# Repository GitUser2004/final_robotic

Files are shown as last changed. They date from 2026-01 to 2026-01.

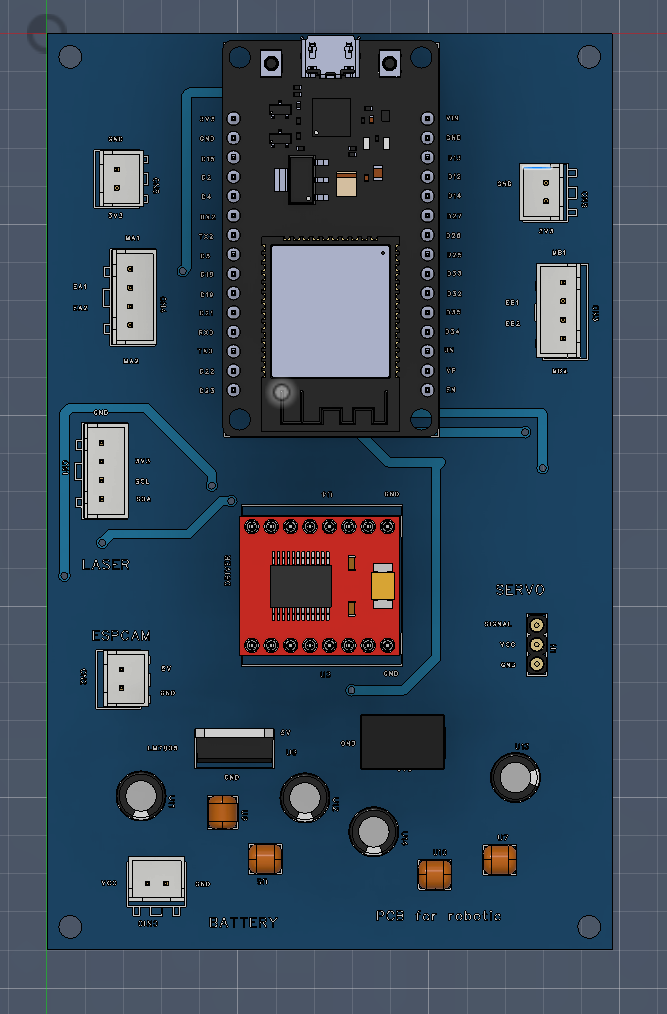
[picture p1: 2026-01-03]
screenshots/Captura de pantalla 2026-01-03 084741.png

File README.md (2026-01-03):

# final_robotic

this repository explains the "Autonomous Mobile Robot for Indoor Medicine Delivery Using Color-Based Vision and Micro-ROS", and implementation of a low-cost autonomous mobile robot for indoor medicine delivery in hospital-like environments. The proposed system integrates color-based computer vision, wireless communication, and reactive navigation to autonomously reach designated rooms identified by color markers while safely avoiding dynamic obstacles. The robot architecture is based on an ESP32 microcontroller, an ESP32-CAM vision system using OpenCV, and a modular control structure compatible with micro-ROS. The delivery task is initiated through a numeric command sent from a user interface, which is mapped to a target color corresponding to a specific room. The robot continuously processes visual data to detect the target color and estimate distance based on detected circular markers, while obstacle avoidance is handled through a low-cost scanning distance sensor. Experimental results demonstrate that the robot can successfully navigate toward target locations, adapt to unexpected obstacles, and complete delivery tasks without human intervention. The modular architecture allows scalability and future integration of advanced localization and planning techniques. This work contributes a flexible, affordable solution for autonomous indoor delivery systems, particularly suited for healthcare and educational environments.

## Environment Setup

### Prerequisites

Ensure you have the following installed:

#### Arduino IDE (Micro-ros)

For programming the esp32 DevKit1 and the espcam its necessary to install the followings libraries in Arduino IDE:

```bash
esp_camera.h
WiFi.h
WebServer.h

# all of this libraries are neccesary only for programming the espcam, otherwise there are additional instrucctions inside the code

WiFi.h
Wire.h
VL53L0X.h
ESP32Servo.h
WebServer.h
PubSubClient.h
ArduinoJson.h
# micro-ROS
micro_ros_arduino.h

# this libraries are for programming the principal esp32, it needs to be updated
```

### Python

```bash
# Install this libraries in python for the espcam
pip install opencv-python==4.11.0.86
pip install numpy==2.3.1

# This dependencies are for the "artificial vision" in the recognition of the colors
```

### ROS2 HUMBLE

```bash

sudo apt install ros-humble-desktop
sudo apt install ros-humble-ros-base
sudo apt install ros-dev-tools
# Check ROS2 Humble installation
ros2 --version
```

In the "esp-cam" folder there are two archives, the .ino is for programming the espcam, this only needs to be with power, the .py in the folder is on ly for visualize the camera in live, otherwise is not neccesary, the camera will works anyway.

### Create Workspace

```bash
# Create and build workspace
mkdir -p ~/autonomous_ws/
cd ~/autonomous_ws/
```

the following steps are neccesary for the first exercise
- copy all the files in the path **ros2/src/dqn_robot_nav/dqn_robot_nav/environment.py** is necessary to copy the folder **src** in the workspace **autonomous_ws**
- make a colcon build
```bash
colcon build
source install/setup.bash
```

once al this steps will be complet it will be ready for running

in one terminal and in the workspace
```bash
ros2 run decision_node decision_node
```
and the interface between the misions and the esp32 will be complete

For testing:
```bash
ros2 topic list
```
to see the nodes.

For the last step is needed to running docker for wifi (for this is neccesary to be in the same network)
```bash
docker run -it --rm --net=host microros/micro-ros-agent:humble udp4 --port 8888 -v6
```

## Interface
The following link is to access to interact with all:
**https://lauch01.github.io/robotic_web/**

To use the interface, the following steps:

1. **Select the room (A, B, C, D)**
2. **Set an hour**

## Extras

In the folders **screenshots**, **3d_models** and **circuit-design** are all the files to build the robot, between .stl, .json and references of components and parts.
- .json files are to import in easyeda pro to view the 3d model

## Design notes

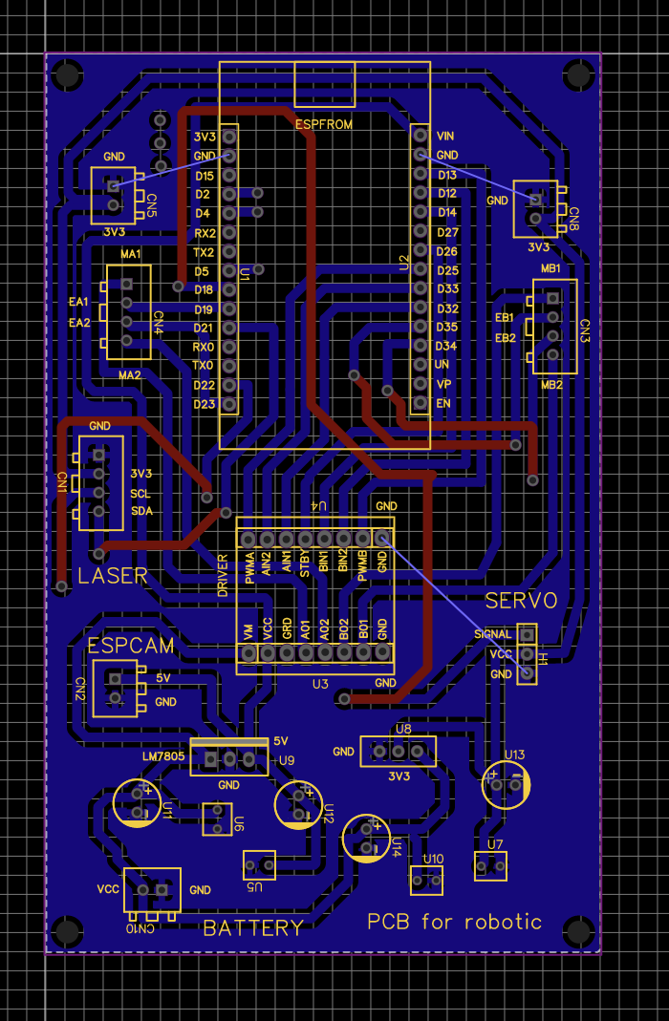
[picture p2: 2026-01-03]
circuit_design/image.png

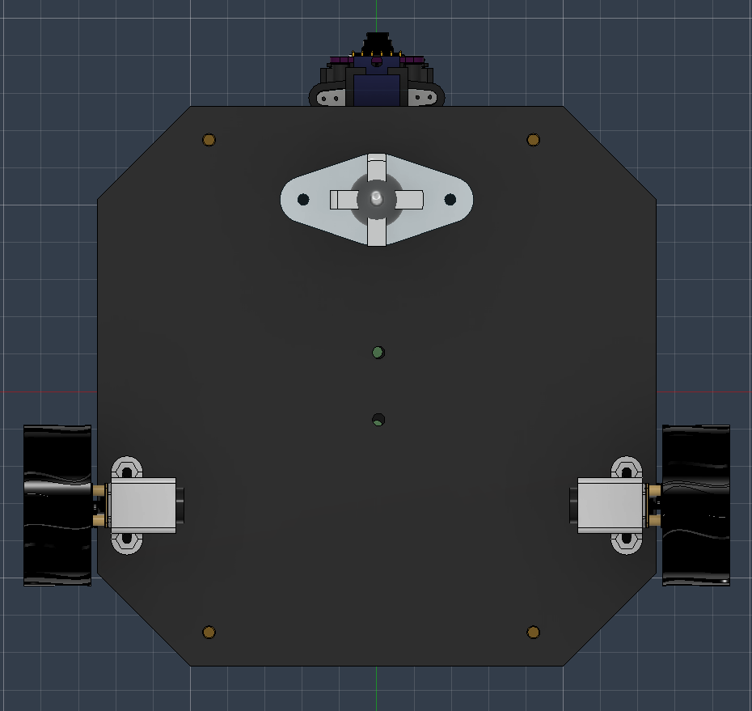
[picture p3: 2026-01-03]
screenshots/Captura de pantalla 2026-01-03 084929.png

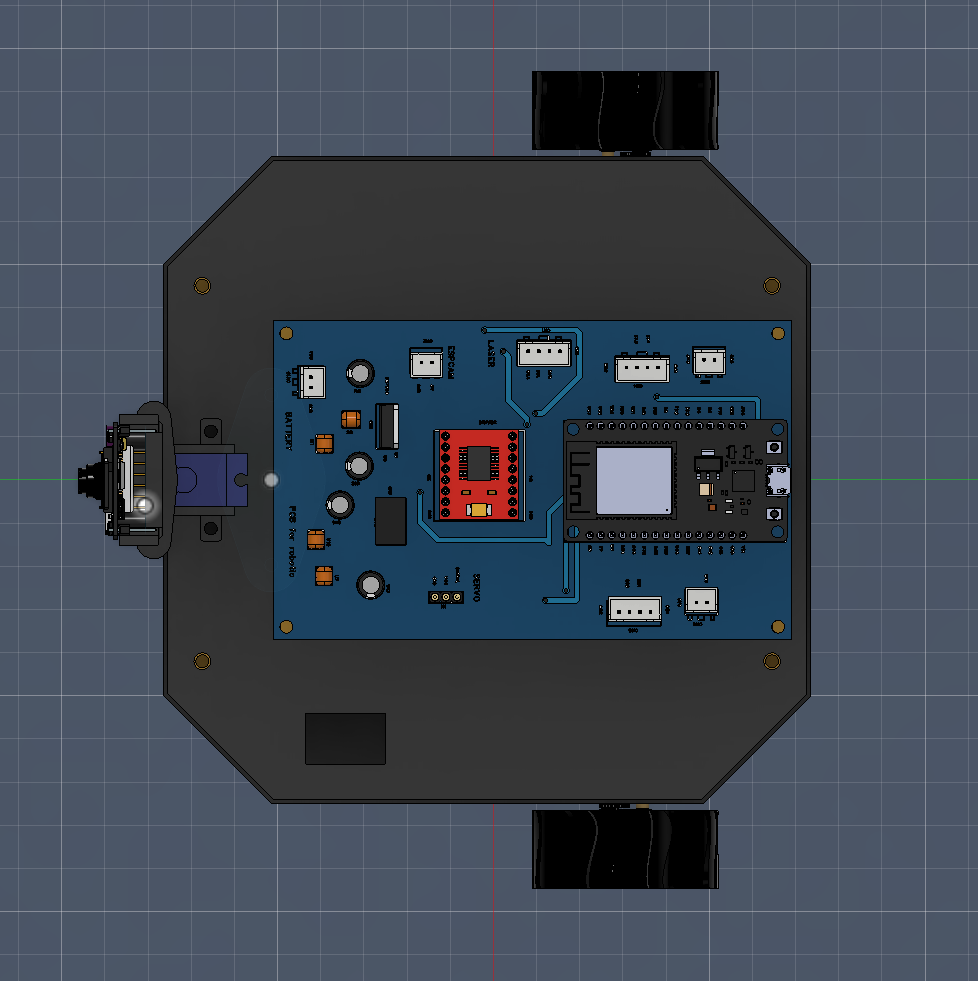
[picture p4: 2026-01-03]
screenshots/Captura de pantalla 2026-01-03 080336.png

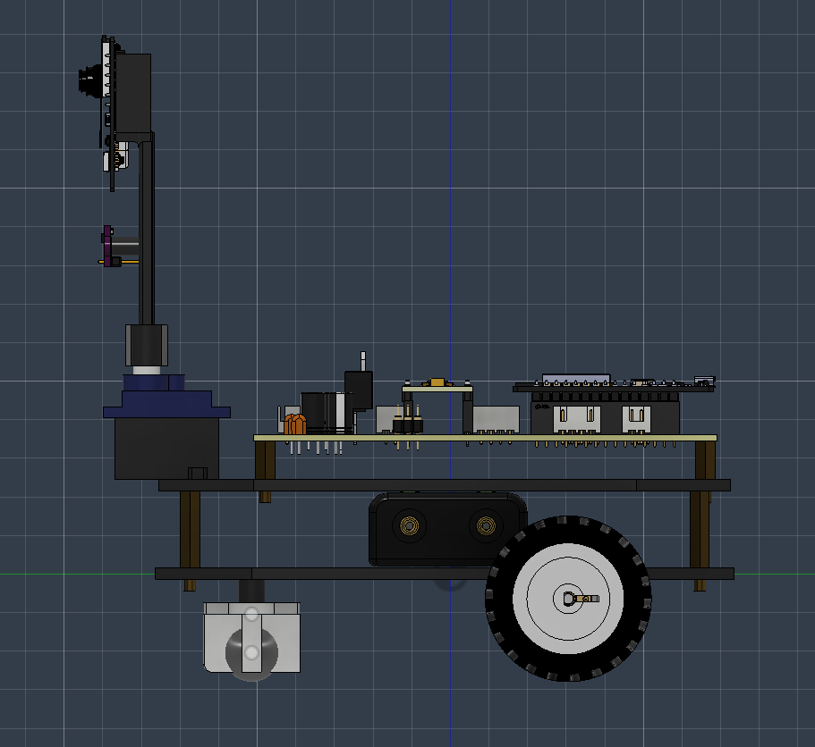
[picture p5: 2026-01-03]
screenshots/Captura de pantalla 2026-01-03 080259.png

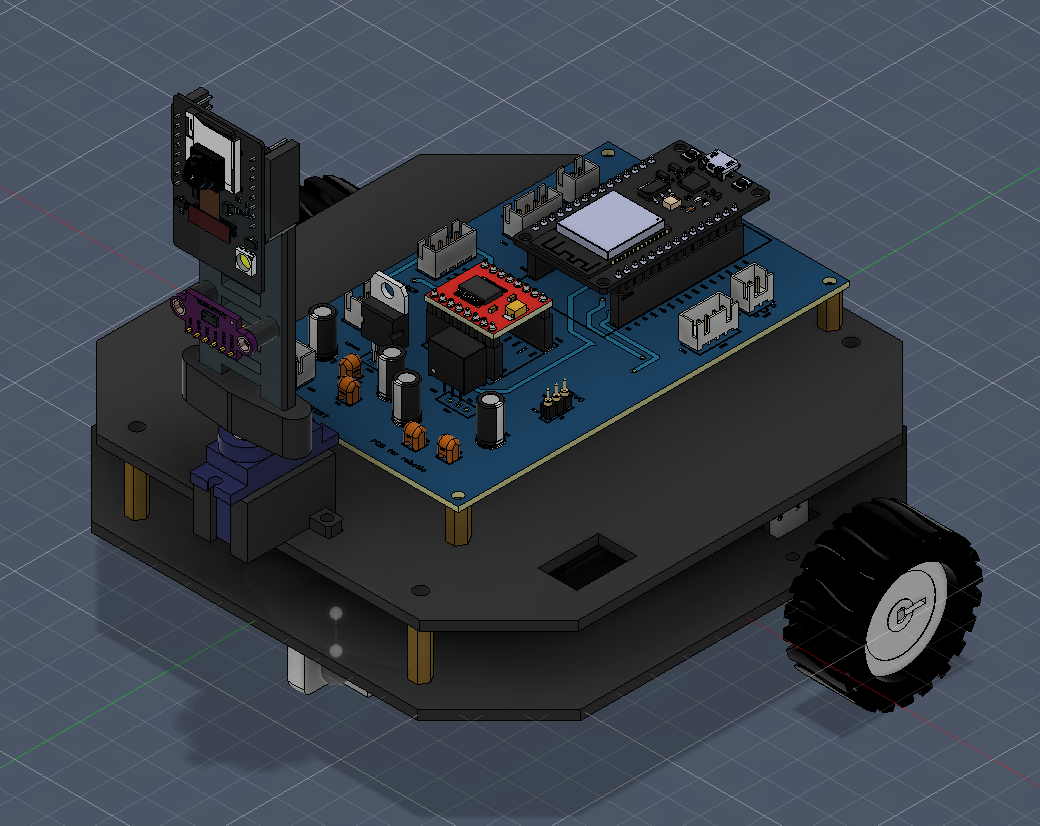
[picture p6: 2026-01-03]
screenshots/Captura de pantalla 2026-01-03 080643.png

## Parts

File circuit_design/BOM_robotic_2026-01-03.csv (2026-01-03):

ID | Name | Designator | Footprint | Quantity | Manufacturer Part | Manufacturer | Supplier | Supplier Part | Price
1 | 2.54-4P ZZDK-H | CN1,CN3,CN4 | CONN-TH_2.54-4P-ZZDK-H | 3 | 2.54-4P ZZDK-H | SHOU HAN(首韩) | LCSC | C49023800 | 0.014
2 | 2.54-2P ZZDK-R 2.54MM CONNECTOR | CN2,CN5,CN8,CN10 | CONN-TH_2.54-2P-ZZDK-R | 4 | 2.54-2P ZZDK-R 2.54mm Connector | SHOU HAN(首韩) | LCSC | C49023793 | 0.015
3 | MH254V-11-03-1196 | H1 | HDR-TH_3P-P2.54-V-M_PZ254-1-03-Z-C | 1 | MH254V-11-03-1196 | XFCN(兴飞) | LCSC | C5184051 | 0.088
4 | PM2.54-YP1D-15A | U1,U2 | HDR-TH_15P-P2.54-V-F | 2 | PM2.54-YP1D-15A | XYECONN(辛译) | LCSC | C22399555 | 0.209
5 | HX PM-254-1-08-Z-8.5 | U3,U4 | HDR-TH_8P-P2.54-V-M-2 | 2 | HX PM-2.54-01-08-Z-H8.5 | hanxia(韩下) | LCSC | C42391638 | 0.12
6 | 1uF | U5,U6,U7,U10 | CAP-TH_L4.2-W3.8-P2.54-D0.5 | 4 | 178MU0010 | KNSCHA(科尼盛) | LCSC | C5632434 | 0.026
7 | LM1117 | U8 | LM1117 | 1
8 | LM7805 | U9 | FOOTPRINT-LM7805 | 1 | LM7805 |  | LM | LM7805
9 | 10uF | U11,U12 | CAP-TH_BD6.3-P2.50-D0.5-FD | 2 | RFS-25V220MF3#N | TAIYO YUDEN(太诱) | LCSC | C399666 | 0.195
10 | 47uF | U13,U14 | CAP-TH_BD6.3-P2.50-D0.5-FD | 2 | RFS-25V220MF3#N | TAIYO YUDEN(太诱) | LCSC | C399666 | 0.195
11 | tb6612 | DRIVER |  | 1
12 | esp32 | ESPFROM |  | 1

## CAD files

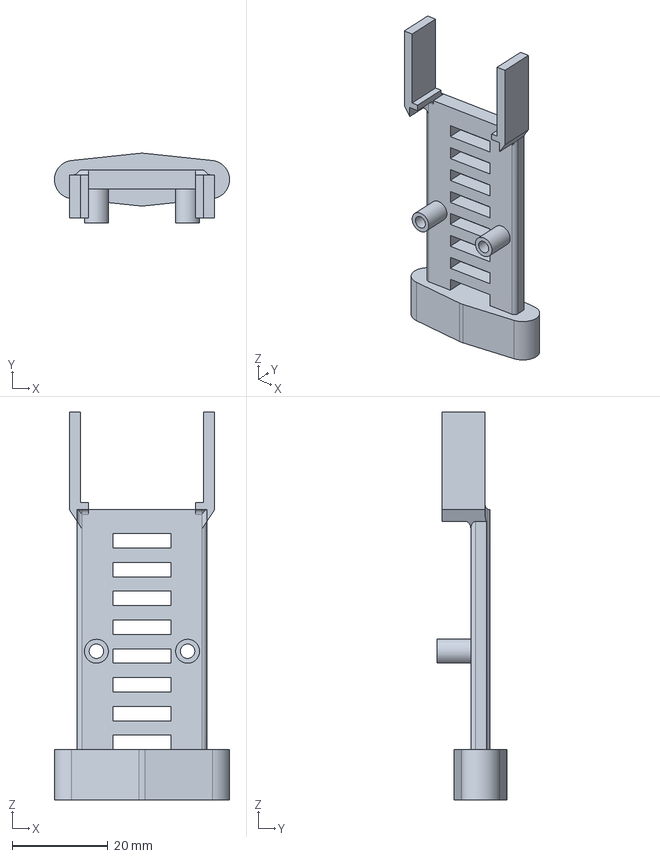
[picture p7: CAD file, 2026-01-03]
3d_models/laser_esp32cam.step
36.5 x 14.5 x 80.8 mm

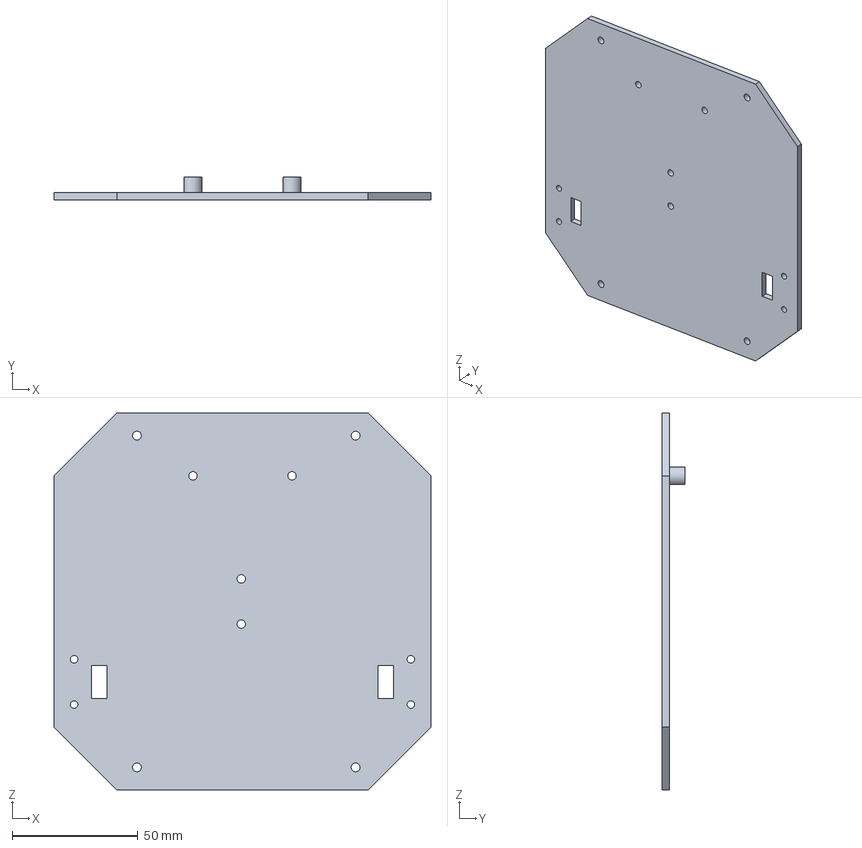
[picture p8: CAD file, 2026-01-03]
3d_models/Nivel_1_N.step
150.0 x 9.00 x 150.0 mm

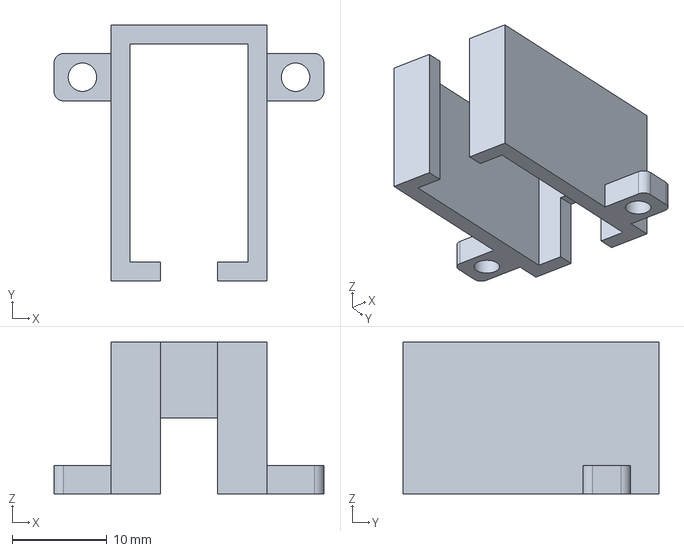
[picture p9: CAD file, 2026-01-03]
3d_models/servo.step
28.5 x 27.0 x 16.0 mm

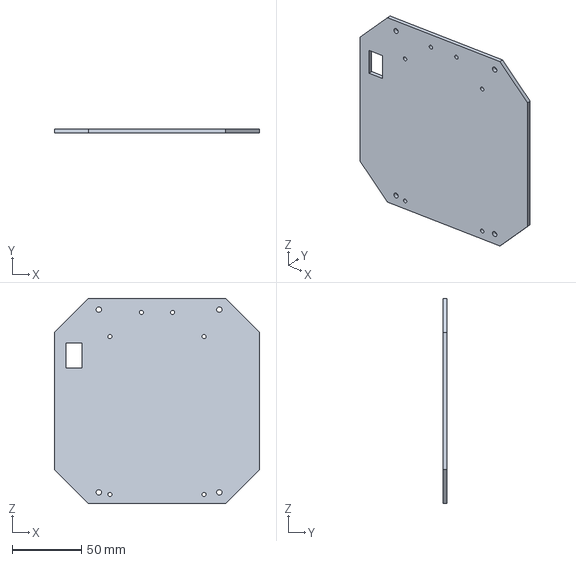
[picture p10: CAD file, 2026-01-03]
3d_models/Nivel_2_N.step
148.0 x 3.00 x 148.0 mm

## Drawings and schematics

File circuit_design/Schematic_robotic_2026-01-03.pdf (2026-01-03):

10 10 11 11 12 12 13 13 14 14 15 15

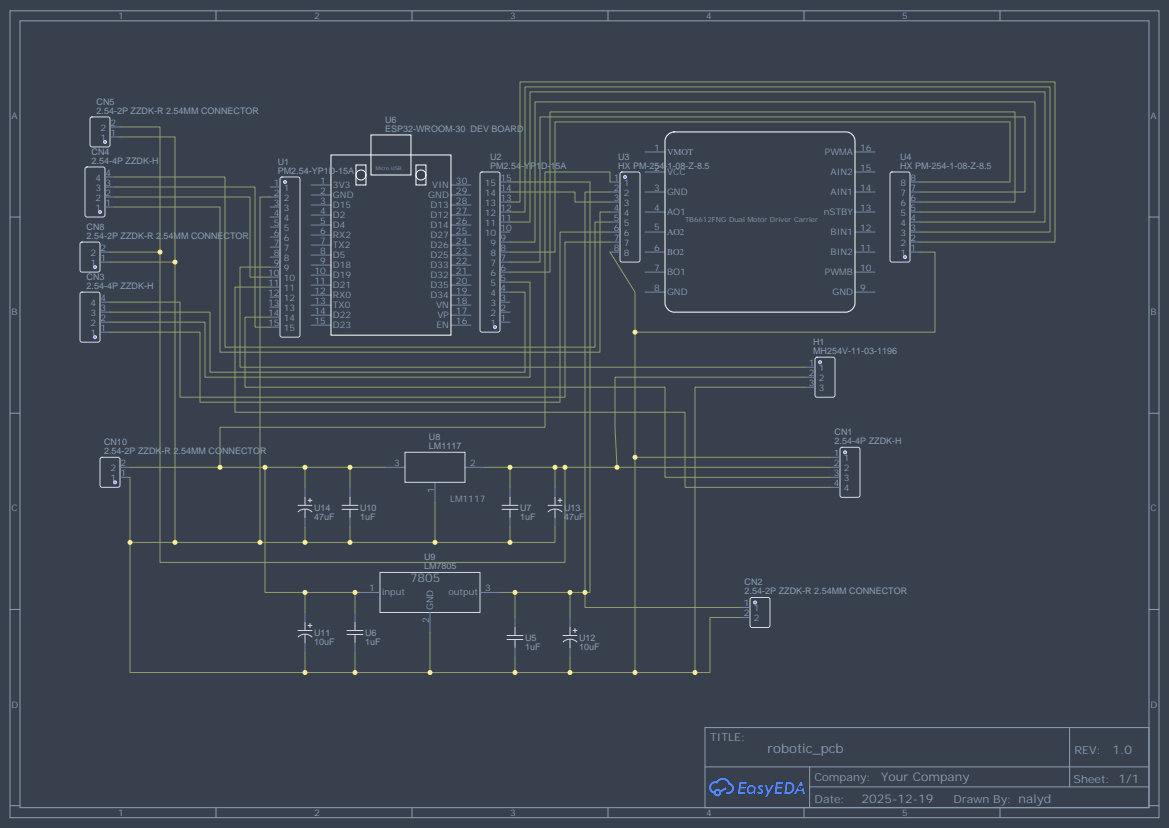
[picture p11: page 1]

TB6612FNG Dual Motor Driver Carrier

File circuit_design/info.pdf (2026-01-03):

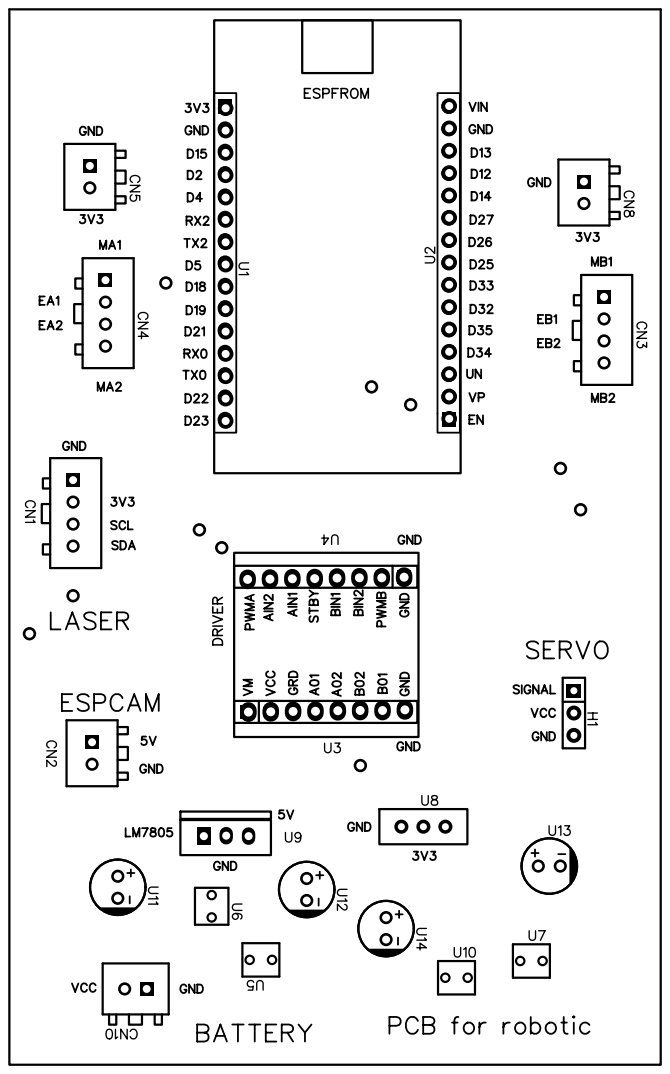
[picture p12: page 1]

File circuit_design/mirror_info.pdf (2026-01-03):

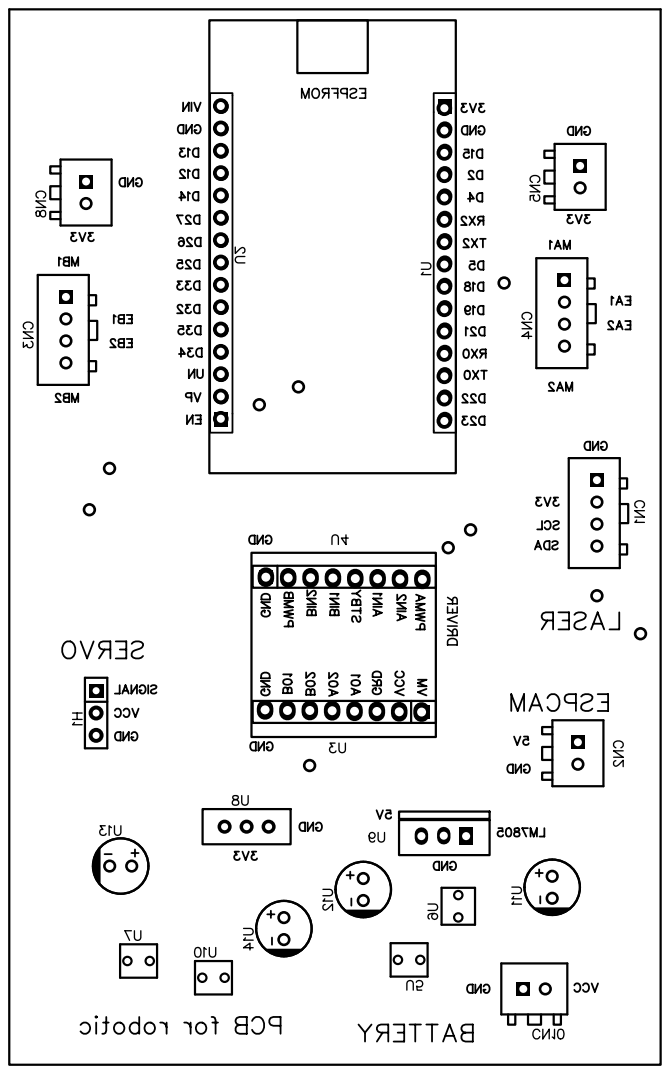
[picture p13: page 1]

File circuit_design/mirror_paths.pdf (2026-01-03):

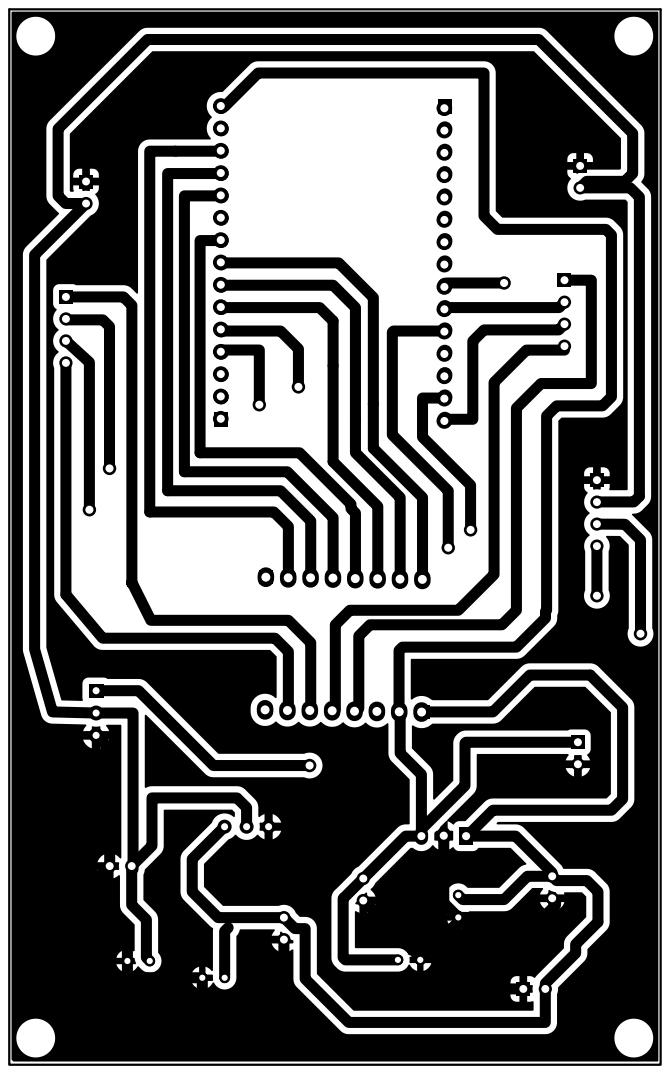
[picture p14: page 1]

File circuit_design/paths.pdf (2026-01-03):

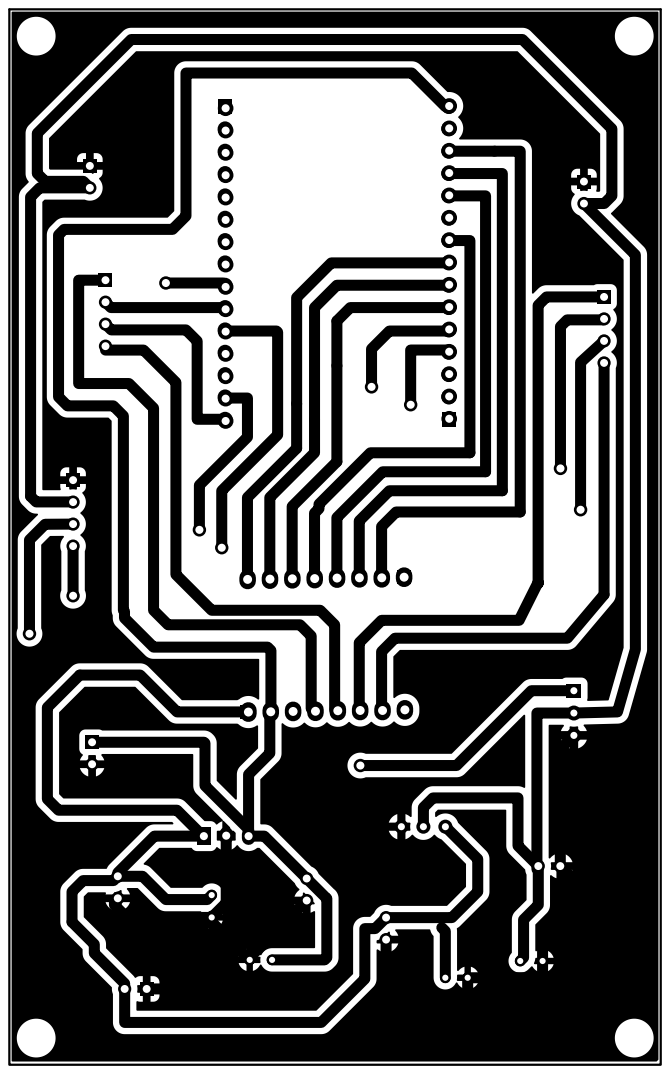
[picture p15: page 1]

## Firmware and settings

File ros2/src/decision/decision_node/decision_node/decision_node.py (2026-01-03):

#!/usr/bin/env python3
"""
Robot Hospital - ESCANEO DE OBSTÁCULOS 
"""
import rclpy
from rclpy.node import Node
from geometry_msgs.msg import Twist
from std_msgs.msg import Float32, Bool, String, Int16
import time
import requests
import threading

class VisionNavigationNode(Node):
    def __init__(self):
        super().__init__('vision_navigation_node')
        
        # ═══════════════════════════════════════════════════════════
        # CONFIGURACIÓN ESP32
        # ═══════════════════════════════════════════════════════════
        self.ESP32_IP = "192.168.100.105"
        self.CAM_IP = "192.168.100.101"
        self.vision_thread = None
        self.vision_running = False
        
        # Datos de visión
        self.color_detectado = False
        self.color_area = 0
        self.color_posicion_x = 0
        self.ultimo_dato_vision = time.time()
        
        # Control de cámara
        self.camera_consecutive_errors = 0
        self.camera_max_errors = 5
        self.camera_available = True
        
        # Control de prioridades
        self.servo_locked = False
        self.vision_paused = False
        
        # ═══════════════════════════════════════════════════════════
        # SUSCRIPCIONES Y PUBLICADORES ROS2
        # ═══════════════════════════════════════════════════════════
        self.distance_front_sub = self.create_subscription(
            Float32, '/distance_front', self.distance_front_callback, 10)
        self.distance_left_sub = self.create_subscription(
            Float32, '/distance_left', self.distance_left_callback, 10)
        self.distance_right_sub = self.create_subscription(
            Float32, '/distance_right', self.distance_right_callback, 10)
        self.odom_sub = self.create_subscription(
            Float32, '/odom', self.odom_callback, 10)
        
        self.cmd_vel_pub = self.create_publisher(Twist, '/cmd_vel', 10)
        self.scan_cmd_pub = self.create_publisher(Bool, '/scan_command', 10)
        self.servo_angle_pub = self.create_publisher(Int16, '/servo_angle', 10)
        
        self.timer = self.create_timer(0.1, self.control_loop)
        
        # ═══════════════════════════════════════════════════════════
        # PARÁMETROS DE NAVEGACIÓN
        # ═══════════════════════════════════════════════════════════
        self.obstacle_threshold = 0.22
        self.safe_distance = 0.28
        
        self.cruise_speed = 0.35
        self.approach_speed = 0.25
        self.turn_speed_45 = 0.72
        self.turn_duration_45 = 1.2
        self.turn_speed_align = 0.40
        self.reverse_speed = -0.30
        self.reverse_duration = 1.5
        
        # ═══════════════════════════════════════════════════════════
        # PARÁMETROS DE ESCANEO MEJORADOS
        # ═══════════════════════════════════════════════════════════
        self.search_interval = 5.0
        self.scan_speed = 10
        self.scan_delay = 0.3
        self.vision_timeout = 2.0
        
        self.area_detected_threshold = 800
        self.area_reached_threshold = 25000
        
        self.centered_time = None
        self.required_centered_duration = 0.3
        self.area_when_centered = 0
        self.min_area_for_centering = 500
        
        self.last_area_log = 0
        
        # ═══════════════════════════════════════════════════════════
        # SISTEMA DE MISIONES
        # ═══════════════════════════════════════════════════════════
        self.mission_state = 'IDLE'
        self.color_objetivo = None
        self.habitacion_visitada = None
        
        # ═══════════════════════════════════════════════════════════
        # DETECCIÓN DE ATASCO Y MOTORES
        # ═══════════════════════════════════════════════════════════
        self.odom_distance = 0.0
        self.last_odom_check = 0.0
        self.last_odom_update_time = time.time()
        self.odom_stuck_start = None
        self.stuck_threshold = 0.008
        self.stuck_timeout = 4.0
        self.odom_initialized = False
        self.odom_init_time = None
        self.odom_warmup_time = 6.0
        self.last_speed_command = 0.0
        
        self.motor_failure_detected = False
        self.motor_recovery_attempts = 0
        self.max_motor_recovery_attempts = 3
        self.odom_timeout = 5.0
        
        # ═══════════════════════════════════════════════════════════
        # ESTADO DEL ROBOT
        # ═══════════════════════════════════════════════════════════
        self.distance_front = 2.0
        self.distance_left = 2.0
        self.distance_right = 2.0
        
        # Control de escaneo mejorado
        self.scan_data_count = 0
        self.scan_data_complete = False
        self.last_scan_data = {
            'left': 2.0,
            'right': 2.0,
            'front': 2.0
        }
        
        self.nav_state = 'WAITING'
        
        # Control de búsqueda visual
        self.last_search_time = 0
        self.scan_angle = 90
        self.scan_direction = 1
        
        # 🆕 Control de escaneo robusto
        self.waiting_scan = False
        self.scan_start_time = 0
        self.scan_timeout = 2.5  # 🔧 Reducido de 3.0 a 2.5s
        self.scan_request_time = 0
        self.scan_retry_count = 0
        self.max_scan_retries = 2
        self.last_scan_attempt = 0
        
        # Control de giros
        self.turn_counter = 0
        self.turn_direction = None
        self.reverse_counter = 0
        
        # PREVENCIÓN DE LOOPS
        self.last_stuck_position = None
        self.stuck_recovery_attempts = 0
        self.max_recovery_attempts = 2
        
        self.get_logger().info("╔═══════════════════════════════════════════════╗")
        self.get_logger().info("║  ROBOT HOSPITAL - ESCANEO ROBUSTO            ║")
        self.get_logger().info("╚═══════════════════════════════════════════════╝")
        self.get_logger().info(f" Esperando comando START_MISSION...\n")
        
        self.start_vision_thread()
        self.mission_thread = threading.Thread(target=self.mission_polling_loop, daemon=True)
        self.mission_thread.start()

    def start_vision_thread(self):
        if not self.vision_running:
            self.vision_running = True
            self.vision_thread = threading.Thread(target=self.vision_processing_loop, daemon=True)
            self.vision_thread.start()

    def mission_polling_loop(self):
        while self.vision_running:
            try:
                r = requests.get(f"http://{self.ESP32_IP}/mission_state", timeout=1)
                if r.status_code == 200:
                    esp_state = r.text.strip().upper()
                    
                    if esp_state == "BUSCANDO" and self.mission_state == 'IDLE':
                        r2 = requests.get(f"http://{self.ESP32_IP}/target", timeout=1)
                        if r2.status_code == 200:
                            color = r2.text.strip().upper()
                            if color in ["ROJO", "VERDE", "AZUL"]:
                                self.color_objetivo = color
                                self.mission_state = 'GOING_TO_ROOM'
                                self.nav_state = 'SEARCHING'
                                self.last_search_time = time.time()
                                self.vision_paused = False
                                self.camera_consecutive_errors = 0
                                self.camera_available = True
                                self.stuck_recovery_attempts = 0
                                self.motor_failure_detected = False
                                self.motor_recovery_attempts = 0
                                self.scan_retry_count = 0  
                                self.get_logger().info(f"MISIÓN: Ir a habitación {color}")
                    
                    elif esp_state == "PAUSA" and self.mission_state == 'GOING_TO_ROOM':
                        self.mission_state = 'AT_ROOM'
                        self.habitacion_visitada = self.color_objetivo
                        self.nav_state = 'WAITING'
                        self.vision_paused = True
                        self.get_logger().info(f"Llegó a habitación {self.habitacion_visitada}")
                    
                    elif esp_state == "VOLVER" and self.mission_state == 'AT_ROOM':
                        self.color_objetivo = "AMARILLO"
                        self.mission_state = 'RETURNING_TO_WAREHOUSE'
                        self.nav_state = 'SEARCHING'
                        self.last_search_time = time.time()
                        self.vision_paused = False
                        self.camera_consecutive_errors = 0
                        self.camera_available = True
                        self.stuck_recovery_attempts = 0
                        self.motor_failure_detected = False
                        self.motor_recovery_attempts = 0
                        self.scan_retry_count = 0  
                        if hasattr(self, '_yellow_close_confirmed'):
                            delattr(self, '_yellow_close_confirmed')
                        self.get_logger().info(f"RETORNO: Buscando almacén (AMARILLO)")
                    
                    elif esp_state == "IDLE" and self.mission_state == 'RETURNING_TO_WAREHOUSE':
                        self.mission_state = 'AT_WAREHOUSE'
                        self.nav_state = 'WAITING'
                        self.color_objetivo = None
                        self.vision_paused = True
                        self.get_logger().info(f"Llegó a almacén")
                        time.sleep(1)
                        self.mission_state = 'IDLE'
                        
            except:
                pass
            
            time.sleep(0.3)

    def vision_processing_loop(self):
        import cv2
        import numpy as np
        
        CAM_URL = f"http://{self.CAM_IP}/capture"
        kernel = np.ones((5,5), np.uint8)
        
        DP = 1.2
        MIN_DIST = 60
        P1 = 120
        P2 = 18
        MIN_R = 12
        MAX_R = 180
        
        while self.vision_running:
            if (self.vision_paused or 
                self.servo_locked or 
                self.color_objetivo is None or 
                self.nav_state in ['WAITING', 'OBSTACLE_STOP', 'OBSTACLE_SCAN', 
                                   'TURNING', 'STUCK_REVERSE']):
                time.sleep(0.3)
                continue
            
            if self.camera_consecutive_errors >= self.camera_max_errors:
                if not self.camera_available:
                    time.sleep(2.0)
                    self.camera_consecutive_errors = 0
                    self.get_logger().info("📷 Reintentando cámara...")
                self.camera_available = False
            
            try:
                r = requests.get(CAM_URL, timeout=2)
                if r.status_code != 200:
                    self.camera_consecutive_errors += 1
                    continue
                
                try:
                    img = cv2.imdecode(np.frombuffer(r.content, np.uint8), cv2.IMREAD_COLOR)
                except:
                    self.camera_consecutive_errors += 1
                    time.sleep(0.5)
                    continue
                
                if img is None:
                    self.camera_consecutive_errors += 1
                    continue
                
                if self.camera_consecutive_errors > 0:
                    self.get_logger().info("✓ Cámara reconectada")
                self.camera_consecutive_errors = 0
                self.camera_available = True
                
                h, w = img.shape[:2]
                hsv = cv2.cvtColor(img, cv2.COLOR_BGR2HSV)
                hsv = cv2.GaussianBlur(hsv, (5,5), 0)
                
                if self.color_objetivo == "ROJO":
                    m1 = cv2.inRange(hsv, (0,120,70), (10,255,255))
                    m2 = cv2.inRange(hsv, (170,120,70), (180,255,255))
                    mask = m1 + m2
                elif self.color_objetivo == "VERDE":
                    mask = cv2.inRange(hsv, (36,50,70), (89,255,255))
                elif self.color_objetivo == "AZUL":
                    mask = cv2.inRange(hsv, (90,50,70), (128,255,255))
                elif self.color_objetivo == "AMARILLO":
                    mask = cv2.inRange(hsv, (20,100,150), (30,255,255))
                else:
                    continue
                
                mask = cv2.morphologyEx(mask, cv2.MORPH_OPEN, kernel)
                mask = cv2.morphologyEx(mask, cv2.MORPH_CLOSE, kernel)
                
                mask_blur = cv2.GaussianBlur(mask, (9, 9), 2)
                circles = cv2.HoughCircles(
                    mask_blur, cv2.HOUGH_GRADIENT,
                    dp=DP, minDist=MIN_DIST, param1=P1, param2=P2,
                    minRadius=MIN_R, maxRadius=MAX_R
                )
                
                if circles is not None:
                    circles = np.uint16(np.around(circles[0]))
                    best = max(circles, key=lambda c: c[2])
                    x, y, rad = best
                    
                    self.color_detectado = True
                    self.color_area = int(np.pi * (rad ** 2))
                    
                    if self.color_objetivo == "AMARILLO":
                        if self.color_area > 15000 and not hasattr(self, '_yellow_close_confirmed'):
                            self.get_logger().warn(f"Amarillo: área sospechosa {self.color_area} - requiere verificación")
                            self.color_area = int(self.color_area * 0.3)
                    
                    center_x = w / 2
                    offset = x - center_x
                    threshold = w * 0.15
                    
                    if offset < -threshold:
                        self.color_posicion_x = -1
                    elif offset > threshold:
                        self.color_posicion_x = 1
                    else:
                        self.color_posicion_x = 0
                    
                    self.ultimo_dato_vision = time.time()
                else:
                    self.color_detectado = False
                    self.color_area = 0
                
            except requests.exceptions.Timeout:
                self.camera_consecutive_errors += 1
                if self.camera_consecutive_errors == self.camera_max_errors:
                    self.get_logger().warn(f"Cámara no responde")
            except Exception as e:
                self.camera_consecutive_errors += 1
                if "JPEG" not in str(e) and "extraneous bytes" not in str(e):
                    self.get_logger().error(f"Error visión: {e}")
            
            time.sleep(0.2)

    def distance_front_callback(self, msg):
        self.distance_front = msg.data
        if self.waiting_scan:
            self.last_scan_data['front'] = msg.data
            self.scan_data_count += 1
            self.get_logger().info(f"Escaneo recibido: FRENTE = {msg.data:.2f}m (datos: {self.scan_data_count}/3)")

    def distance_left_callback(self, msg):
        self.distance_left = msg.data
        if self.waiting_scan:
            self.last_scan_data['left'] = msg.data
            self.scan_data_count += 1
            self.get_logger().info(f"Escaneo recibido: IZQUIERDA = {msg.data:.2f}m (datos: {self.scan_data_count}/3)")

    def distance_right_callback(self, msg):
        self.distance_right = msg.data
        if self.waiting_scan:
            self.last_scan_data['right'] = msg.data
            self.scan_data_count += 1
            self.get_logger().info(f"Escaneo recibido: DERECHA = {msg.data:.2f}m (datos: {self.scan_data_count}/3)")

    def odom_callback(self, msg):
        prev_odom = self.odom_distance
        self.odom_distance = msg.data
        
        if msg.data != prev_odom:
            self.last_odom_update_time = time.time()
            if self.motor_failure_detected:
                self.get_logger().info("✓ Motores respondiendo nuevamente")
                self.motor_failure_detected = False
                self.motor_recovery_attempts = 0
        
        if not self.odom_initialized and msg.data > 0.0:
            self.odom_initialized = True
            self.odom_init_time = time.time()
            self.last_odom_check = msg.data
        elif self.odom_initialized and msg.data == 0.0:
            self.odom_initialized = False
            self.odom_init_time = None
            self.odom_stuck_start = None

    def set_servo_angle(self, angle):
        if not self.servo_locked:
            msg = Int16()
            msg.data = int(angle)
            self.servo_angle_pub.publish(msg)
            self.scan_angle = angle

    def request_obstacle_scan(self):
        """🔧 Solicitar escaneo con logging detallado"""
        self.servo_locked = True
        self.vision_paused = True
        
        self.scan_data_count = 0
        self.scan_data_complete = False
        
        msg = Bool()
        msg.data = True
        self.scan_cmd_pub.publish(msg)
        self.waiting_scan = True
        self.scan_start_time = time.time()
        self.scan_request_time = time.time()
        
        self.get_logger().info("Escaneo solicitado al ESP32...")
        self.get_logger().info(f"   → Timeout: {self.scan_timeout}s")
        self.get_logger().info(f"   → Intento: {self.scan_retry_count + 1}/{self.max_scan_retries + 1}")

    def check_scan_complete(self):
        """Verificar si recibimos las 3 lecturas"""
        return self.scan_data_count >= 3

    def analyze_obstacle_scan(self):
        """Análisis: siempre girar hacia el lado más libre"""
        front = self.last_scan_data['front']
        left = self.last_scan_data['left']
        right = self.last_scan_data['right']
        
        self.get_logger().info(
            f"Escaneo completo → F={front:.2f}m, L={left:.2f}m, R={right:.2f}m"
        )
        
        if left > right + 0.10:
            self.get_logger().info(f"↰ Decisión: IZQUIERDA más libre ({left:.2f}m vs {right:.2f}m)")
            return 'LEFT'
        elif right > left + 0.10:
            self.get_logger().info(f"↱ Decisión: DERECHA más libre ({right:.2f}m vs {left:.2f}m)")
            return 'RIGHT'
        else:
            if left > right:
                self.get_logger().info(f"↰ Decisión: IZQUIERDA (empate, {left:.2f}m)")
                return 'LEFT'
            else:
                self.get_logger().info(f"↱ Decisión: DERECHA (empate, {right:.2f}m)")
                return 'RIGHT'

    def fallback_obstacle_decision(self):
        """Decisión de emergencia si el escaneo falla"""
        self.get_logger().warn("Escaneo falló - usando sensores actuales como fallback")
        
        left = self.distance_left
        right = self.distance_right
        front = self.distance_front
        
        self.get_logger().info(f"Lecturas actuales → F={front:.2f}m, L={left:.2f}m, R={right:.2f}m")
        
        if left > right + 0.10:
            self.get_logger().info(f"↰ Fallback: IZQUIERDA ({left:.2f}m)")
            return 'LEFT'
        elif right > left + 0.10:
            self.get_logger().info(f"↱ Fallback: DERECHA ({right:.2f}m)")
            return 'RIGHT'
        else:
            # Si empate, usar el lado que tuvo mejor lectura histórica
            if left >= right:
                self.get_logger().info(f"↰ Fallback: IZQUIERDA (empate)")
                return 'LEFT'
            else:
                self.get_logger().info(f"↱ Fallback: DERECHA (empate)")
                return 'RIGHT'

    def check_if_stuck(self):
        """Detección robusta - NO detectar atasco durante APPROACHING"""
        if self.nav_state not in ['SEARCHING']:
            self.odom_stuck_start = None
            return False
        
        if abs(self.last_speed_command) < 0.15:
            self.odom_stuck_start = None
            return False
        
        if not self.odom_initialized or self.odom_distance == 0.0:
            return False
        
        if self.odom_init_time is not None:
            if time.time() - self.odom_init_time < self.odom_warmup_time:
                return False
        
        if time.time() - self.last_odom_update_time > self.odom_timeout:
            if not self.motor_failure_detected:
                self.get_logger().error("FALLO DE MOTORES: Odometría no actualiza")
                self.motor_failure_detected = True
                self.motor_recovery_attempts += 1
                
                if self.motor_recovery_attempts >= self.max_motor_recovery_attempts:
                    self.get_logger().error("Fallo crítico de motores - requiere reinicio")
                    return False
            
            return False
        
        odom_change = abs(self.odom_distance - self.last_odom_check)
        
        if odom_change > self.stuck_threshold:
            self.odom_stuck_start = None
            self.last_odom_check = self.odom_distance
            return False
        
        if self.odom_stuck_start is None:
            self.odom_stuck_start = time.time()
            self.last_odom_check = self.odom_distance
            return False
        
        if time.time() - self.odom_stuck_start >= self.stuck_timeout:
            self.get_logger().warn("ATASCO DETECTADO")
            return True
        
        return False

    def publish_cmd_vel(self, linear, angular):
        """Publicar con verificación"""
        msg = Twist()
        msg.linear.x = linear
        msg.angular.z = angular
        self.cmd_vel_pub.publish(msg)
        
        self.last_speed_command = linear
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

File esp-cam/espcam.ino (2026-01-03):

#include "esp_camera.h"
#include <WiFi.h>
#include <WebServer.h>

#define CAMERA_MODEL_AI_THINKER
#include "camera_pins.h"

/* In this section its necessary to define the WiFi credentials and server configuration from */

/* ===== WIFI ===== */
const char* ssid = "HOME-GT";
const char* password = "Casa.24GT";

/* ===== SERVER ===== */
WebServer server(80);

/* ===== CAPTURE ===== */
void handleCapture() {
  camera_fb_t * fb = esp_camera_fb_get();
  if (!fb) {
    server.send(500, "text/plain", "Camera capture failed");
    return;
  }

  server.sendHeader("Content-Type", "image/jpeg");
  server.send_P(200, "image/jpeg", (const char*)fb->buf, fb->len);
  esp_camera_fb_return(fb);
}

void setup() {
  Serial.begin(115200);

  camera_config_t config;
  config.ledc_channel = LEDC_CHANNEL_0;
  config.ledc_timer = LEDC_TIMER_0;
  config.pin_d0 = Y2_GPIO_NUM;
  config.pin_d1 = Y3_GPIO_NUM;
  config.pin_d2 = Y4_GPIO_NUM;
  config.pin_d3 = Y5_GPIO_NUM;
  config.pin_d4 = Y6_GPIO_NUM;
  config.pin_d5 = Y7_GPIO_NUM;
  config.pin_d6 = Y8_GPIO_NUM;
  config.pin_d7 = Y9_GPIO_NUM;
  config.pin_xclk = XCLK_GPIO_NUM;
  config.pin_pclk = PCLK_GPIO_NUM;
  config.pin_vsync = VSYNC_GPIO_NUM;
  config.pin_href = HREF_GPIO_NUM;
  config.pin_sccb_sda = SIOD_GPIO_NUM;
  config.pin_sccb_scl = SIOC_GPIO_NUM;
  config.pin_pwdn = PWDN_GPIO_NUM;
  config.pin_reset = RESET_GPIO_NUM;

  config.xclk_freq_hz = 20000000;
  config.pixel_format = PIXFORMAT_JPEG;

  config.frame_size = FRAMESIZE_QVGA;   // 320x240
  config.jpeg_quality = 20;
  config.fb_count = 1;
  config.grab_mode = CAMERA_GRAB_WHEN_EMPTY;
  config.fb_location = CAMERA_FB_IN_DRAM;

  if (esp_camera_init(&config) != ESP_OK) {
    Serial.println("Error inicializando cámara");
    return;
  }

  sensor_t * s = esp_camera_sensor_get();
  s->set_framesize(s, FRAMESIZE_QVGA);

  WiFi.begin(ssid, password);
  while (WiFi.status() != WL_CONNECTED) {
    delay(500);
    Serial.print(".");
  }

  Serial.println("\nWiFi conectado");
  Serial.print("IP: ");
  Serial.println(WiFi.localIP());

  server.on("/capture", HTTP_GET, handleCapture);
  server.begin();

  Serial.println("Servidor listo: n");
}

void loop() {
  server.handleClient();
}
